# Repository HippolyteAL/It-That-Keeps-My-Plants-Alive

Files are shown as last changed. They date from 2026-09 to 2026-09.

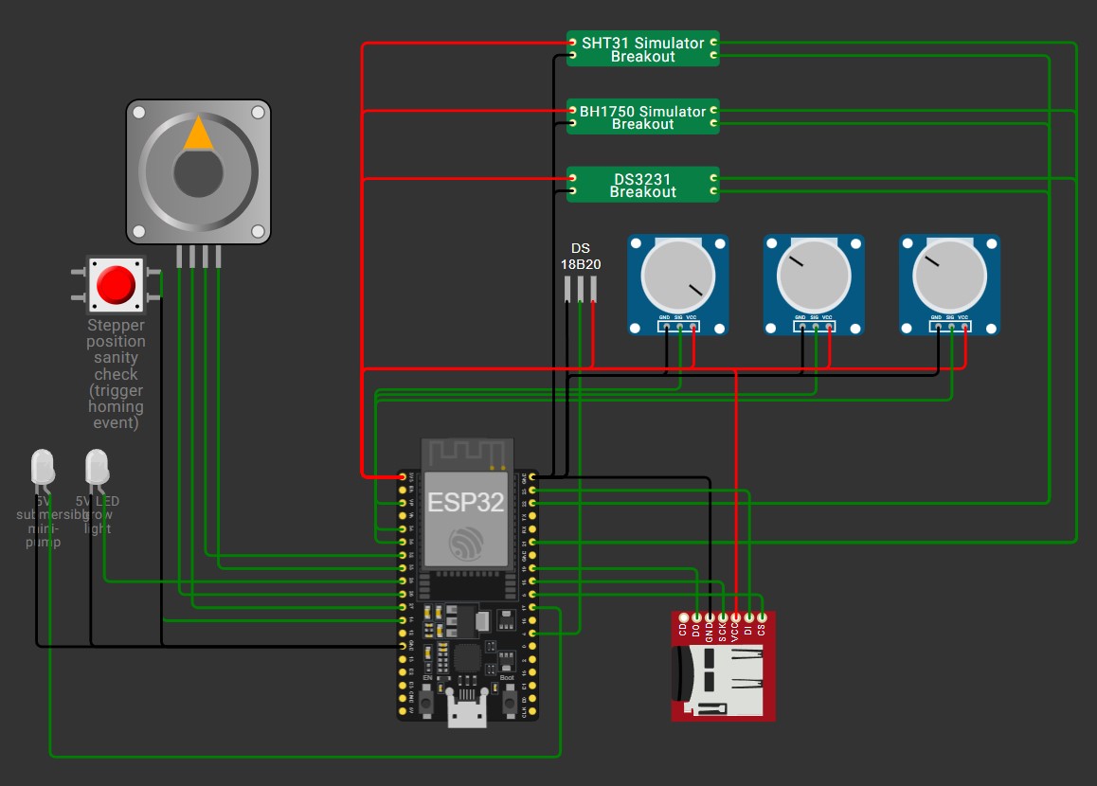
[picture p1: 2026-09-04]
screenshots/diagram_screenshot.jpg

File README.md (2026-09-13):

# It That Keeps My Plants Alive

## Introduction

My houseplants met their untimely demise to the hands of not receiving the proper amount of water, so I have come up with a solution. It's a machine that monitors temperature, humidity and light and controls a grow light and water arm to make sure the plants stay alive. There are also multiple extra sensors to gather various data on ambient humidity/temperature and soil temperature that are unnecessary for the actuator, but I wanted to make something that also gathers data for fun.

## Wokwi simulation

Before getting into any expenses, I decided to run this whole thing in a Wokwi simulation  linked here:

https://wokwi.com/projects/475088516800323585

To run the simulation, download the it_that_keeps_my_plants_alive.bin file from the repo and use the command "F1 -> Upload Firmware and Start Simulation" , uploading the .bin file into the browser.

The soil moisture sensors are replaced with potentiometers in the simulation, so the can be moved around to make the machine water different positions. The downside is that they arent automatically updated when watered and as such are watered repeatedly until manually raised above 30% moisture. All the numerical values are arbitrary placeholders, because real numbers would depend on the real plants being watered. Also the pump is an LED, because it is more visual for a simulation.

This also serves as a good way to picture what this machine is.

## Software architecture
Located in main/, the schematic.pdf pages mirror the structure of the code files.

File | Purpose
---|---
main.c | Main
sensors.c | Periodic sampling of moisture/temp/humidity/light
actuators.c | Pump control + RTC-driven light schedule + stepper control
storage.c | CSV to SD card

## Build

- Install ISP-IDF v5.5.5
- In an ESP-IDF terminal, run the commands:
    - idf.py set-target esp32
    - idf.py build

## Hardware

See the Schematic.pdf, here's an estimate of materials cost (sourced from canadian prices, 2026):

Piece | Function | Cost (pre-tax, CAD)
--- | --- | ---
ESP32-WROOM32E | Main controller | 13$
28BYJ-48 stepper + ULN2003 driver | Motion control | 4$
2x Logic-level MOFSETs | Actuator activation | 2x5$
5V LED grow light | light | 10-20$
5V submersible pump | water | 12$
push switch | control | 1$
DS18B20 | Soil temperature sensor | 15$
3x Soil moisture sensor | Moisture sensor | 3x5$
SHT31 | Ambient temperature and humidity sensor | 12-18$
BH1750 | Light sensor | 7$
DS3231 | Power independant time tracking | 7$
MicroSD module + chip | Logging | 14$
3x 10kΩ resistor | Circuits | variable (bulk vs indiv.)
4.7kΩ resistor | Circuits | variable
1μF capacitor | Circuits | variable
Flyback Diode | Circuits | variable
TOTAL | | ~130 $CAD + electronics + tx

Tools (testing) | Importance | Cost (pre-tax)
--- | --- | ---
Breadboard kit | Essential | 20$
Extra breadboard | Useful | 8$
Multimeter | Variable | 25$
Perfboard | Essential | 2$
TOTAL | | 22-55 $CAD + tx

The total can be brought under 100 $CAD easily if you borrow / already have appropriate tools (or above the current estimate if you choose a more permanent/long term custom circuit board). You can also cut ~50 $CAD by bailing on the purely data gathering part of the project (MicroSD, SHT31, DS18B20).

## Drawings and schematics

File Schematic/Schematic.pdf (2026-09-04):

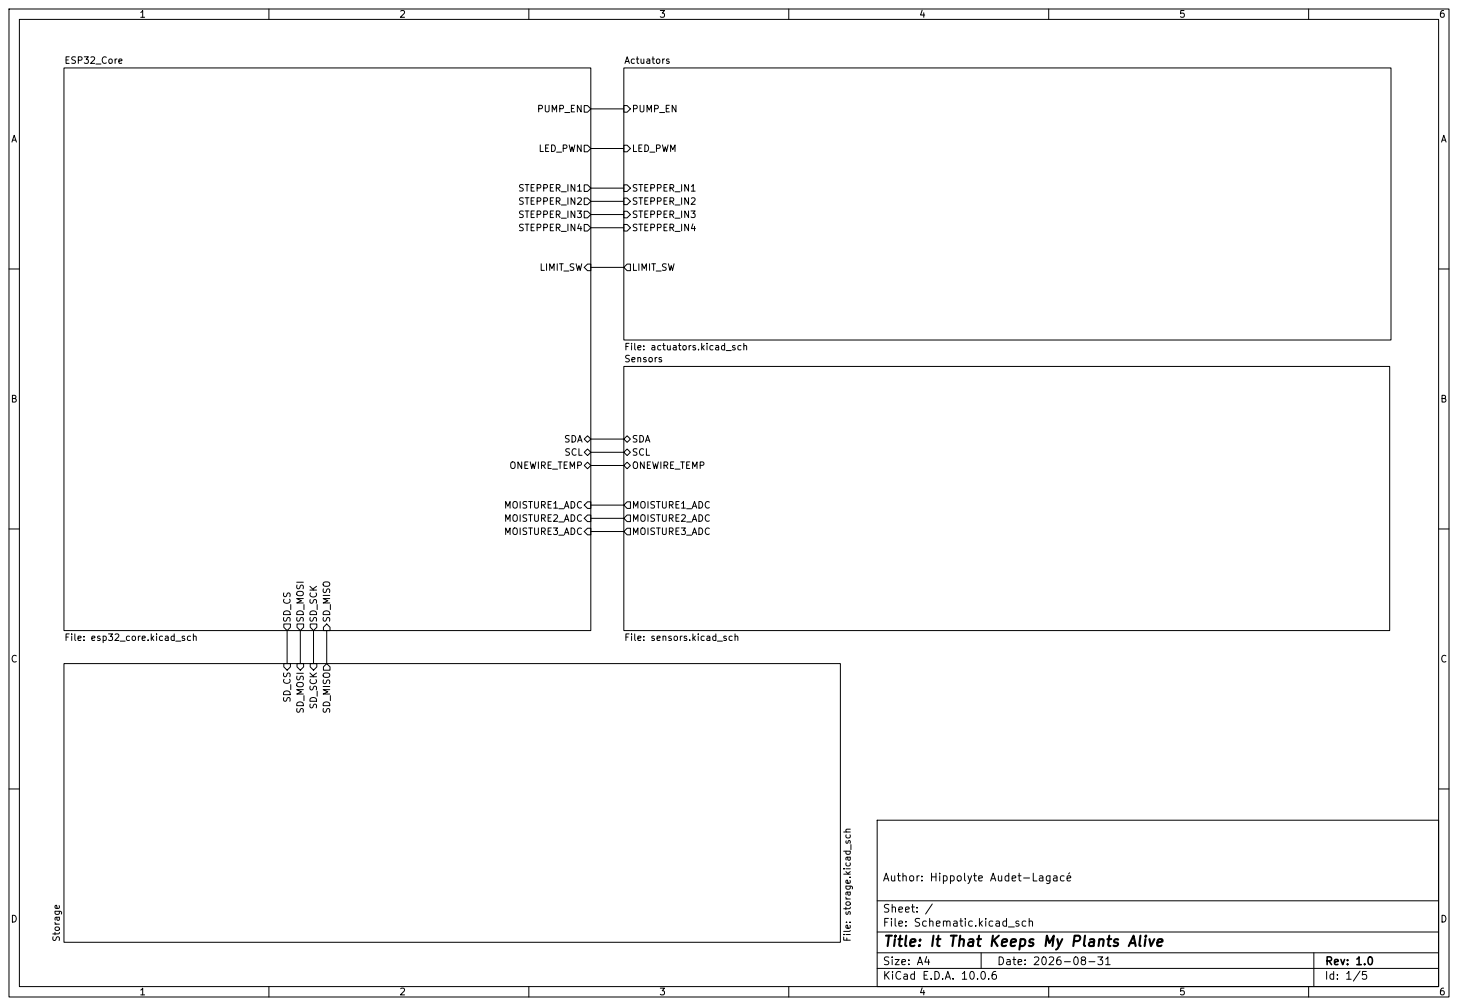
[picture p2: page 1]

Author: Hippolyte Audet-Lagacé MOISTURE1_ADC MOISTURE2_ADC MOISTURE3_ADC ONEWIRE_TEMP

Sheet: /
File: Schematic.kicad_sch
Title: It That Keeps My Plants Alive

Size: A4 | Rev: 1.0
KiCad E.D.A. 10.0.6 | Id: 1/5

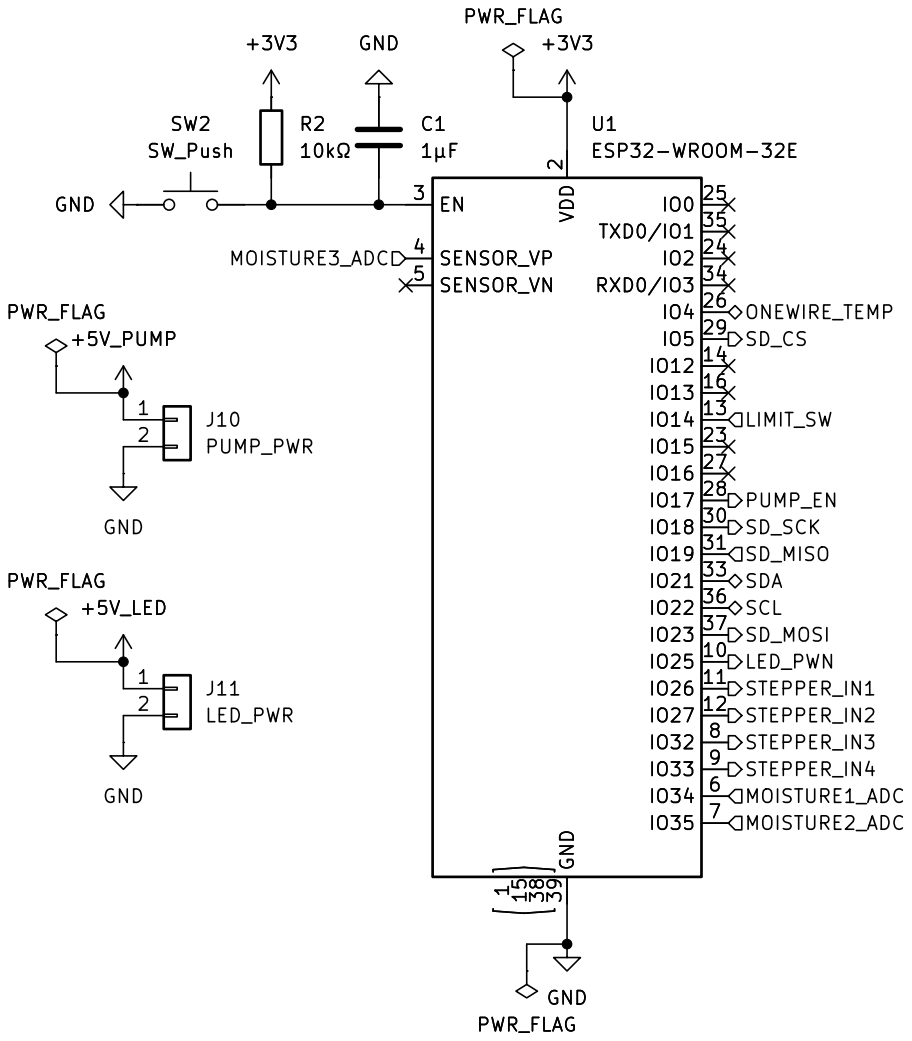
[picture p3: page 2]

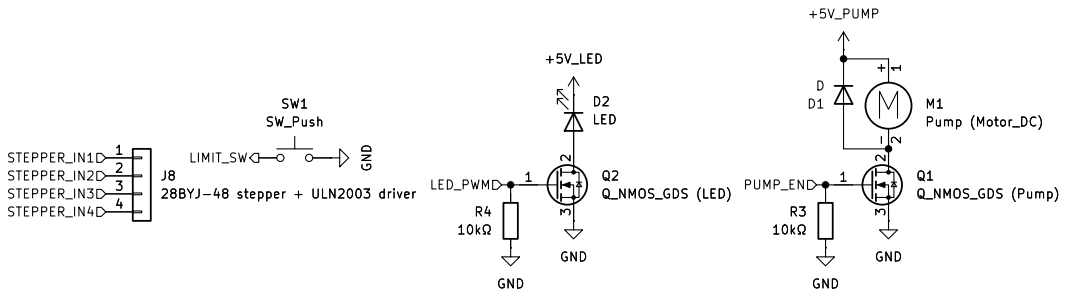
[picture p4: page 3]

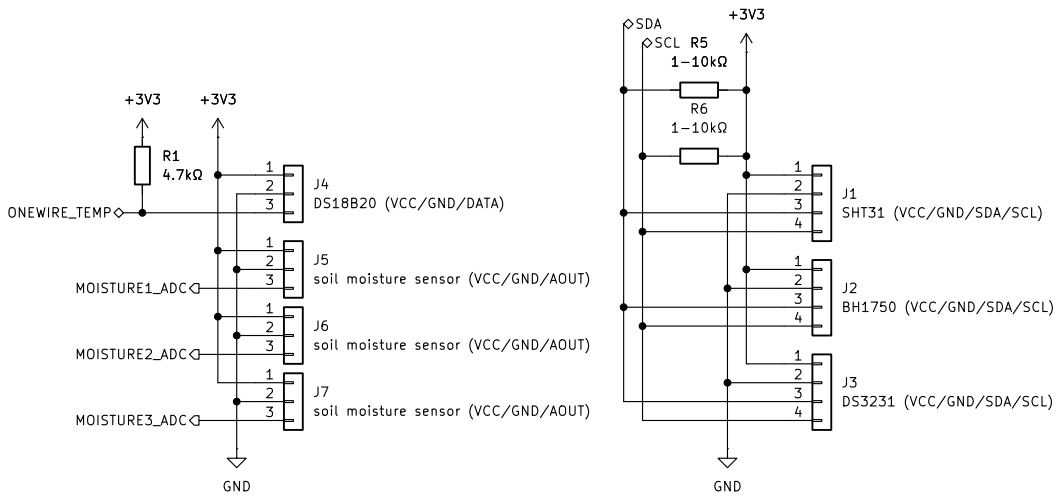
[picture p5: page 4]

soil moisture sensor (VCC/GND/AOUT) 1
J4DS18B20 (VCC/GND/DATA) 1

J3DS3231 (VCC/GND/SDA/SCL) 1
SHT31 (VCC/GND/SDA/SCL) 1

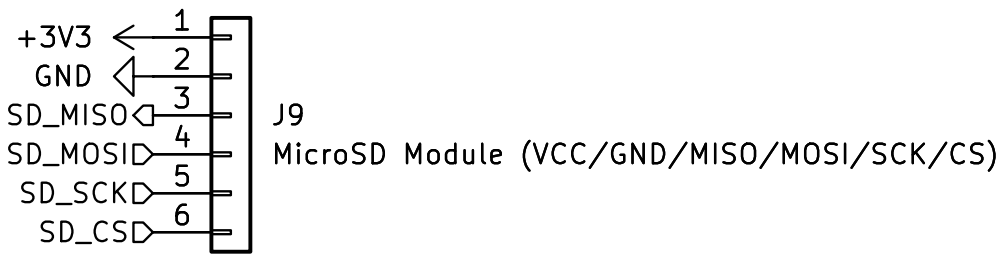
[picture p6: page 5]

J9MicroSD Module (VCC/GND/MISO/MOSI/SCK/CS) SD_CS
SD_MOSI SD_MISO

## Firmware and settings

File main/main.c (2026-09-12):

#include <stdio.h>
#include <stdbool.h>

#include "freertos/FreeRTOS.h"
#include "freertos/task.h"
#include "freertos/semphr.h"

#include "esp_log.h"
#include "esp_err.h"

#include "pinout.h"
#include "sensors.h"
#include "actuators.h"
#include "storage.h"

/*
esp32_core.kicad_sch. Defines and executes the shared system state, task scheduling, 
and the plant-care control loop.
*/

static const char *TAG = "main";

//TODO placeholder values, revisit once sensors are calibrated
#define SENSOR_POLL_PERIOD_MS       (5 * 1000)
#define CONTROL_LOOP_PERIOD_MS      (10 * 1000)
#define LOGGING_PERIOD_MS           (15 * 1000) // TODO: Should be every 15 minutes (15 x 60000) outside of testing ?

#define MOISTURE_LOW_THRESHOLD_PCT  30.0f
#define TARGET_AMBIENT_LUX          8000.0f

// Shared system state: written by sensor_task, read by control_task and logging_task. 
// Guarded by a mutex since it's touched from three tasks.
typedef struct {
    sensor_readings_t   latest;
    SemaphoreHandle_t   mutex;
} system_state_t;

static system_state_t s_state;

static void sensor_task(void *arg);
static void control_task(void *arg);
static void logging_task(void *arg);

void app_main(void) {
    ESP_LOGI(TAG, "boot: It That Keeps My Plants Alive");

    s_state.mutex = xSemaphoreCreateMutex();
    configASSERT(s_state.mutex != NULL);

    ESP_ERROR_CHECK(sensors_init());
    ESP_ERROR_CHECK(actuators_init());
    ESP_ERROR_CHECK(storage_init());
    // ESP_ERROR_CHECK(actuators_stepper_home());

    xTaskCreate(sensor_task,  "sensor_task",  4096, NULL, 5, NULL);
    xTaskCreate(control_task, "control_task", 4096, NULL, 5, NULL);
    xTaskCreate(logging_task, "logging_task", 4096, NULL, 4, NULL);
}

static void sensor_task(void *arg) {
    for (;;) {
        sensor_readings_t reading;
        if (sensors_read_all(&reading) == ESP_OK) {
            xSemaphoreTake(s_state.mutex, portMAX_DELAY);
            s_state.latest = reading;
            xSemaphoreGive(s_state.mutex);

            // testing wokwi setup
            ESP_LOGI(TAG, "sensor_task: rtc=%" PRId64 " soil_temp=%.2fC moisture=[%.1f, %.1f, %.1f]%% " "ambient=%.2fC/%.1f%%RH lux=%.1f",
                    reading.rtc_unix_time, reading.soil_temp_c, reading.soil_moisture_pct[0], reading.soil_moisture_pct[1], 
                    reading.soil_moisture_pct[2], reading.ambient_temp_c, reading.ambient_humidity_pct, reading.ambient_lux);
        } else {
            ESP_LOGW(TAG, "sensor_task: read_all failed");
        }
        vTaskDelay(pdMS_TO_TICKS(SENSOR_POLL_PERIOD_MS));
    }
}

static void control_task(void *arg) {
    for (;;) {
        sensor_readings_t reading;
        xSemaphoreTake(s_state.mutex, portMAX_DELAY);
        reading = s_state.latest;
        xSemaphoreGive(s_state.mutex);

        if (reading.valid) {
            /* TODO: this reacts the instant a probe dips below threshold. The final goal is to require it to stay below threshold for a
            minimum duration first, so a single noisy/borderline reading doesn't trigger a watering cycle, and so watering cycles can be
            potentially executed all at once. This might require moving the homing call outside the watering call to here. */
            for (uint8_t zone = 0; zone < 3; zone++) {
                if (reading.soil_moisture_pct[zone] < MOISTURE_LOW_THRESHOLD_PCT) {
                    ESP_LOGI(TAG, "control_task: zone %u dry (%.1f%%), watering", zone, reading.soil_moisture_pct[zone]);
                    esp_err_t err = actuators_water_zone(zone, reading.rtc_unix_time);
                    if (err != ESP_OK) {
                        ESP_LOGW(TAG, "control_task: water_zone(%u) failed: %s", zone, esp_err_to_name(err));
                    }
                }
            }
            
            uint8_t led_percent = 0;
            actuators_set_led_for_target_lux(reading.ambient_lux, TARGET_AMBIENT_LUX, &led_percent);
            ESP_LOGI(TAG, "control_task: ambient=%.1flux led=%u%% (target=%.0flux)", reading.ambient_lux, led_percent, TARGET_AMBIENT_LUX);
        }

        if (actuators_limit_switch_triggered()) {
            // TODO: decide what a manual homing-button press should do mid-run.
            ESP_LOGI(TAG, "control_task: homing button pressed");
        }

        vTaskDelay(pdMS_TO_TICKS(CONTROL_LOOP_PERIOD_MS));
    }
}

static void logging_task(void *arg) {
    for (;;) {
        sensor_readings_t reading;
        xSemaphoreTake(s_state.mutex, portMAX_DELAY);
        reading = s_state.latest;
        xSemaphoreGive(s_state.mutex);

        if (reading.valid) {
            esp_err_t err = storage_log_reading(&reading);
            if (err != ESP_OK) {
                ESP_LOGW(TAG, "logging_task: write failed (%s)", esp_err_to_name(err));
            }
        }

        vTaskDelay(pdMS_TO_TICKS(LOGGING_PERIOD_MS));
    }
}

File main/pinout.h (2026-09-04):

#ifndef PINOUT_H
#define PINOUT_H

/*
Central pin / bus configuration for the "It That Keeps My Plants Alive" project. Mirrors the net names used on the ESP32_Core sheet of
Schematic.kicad_sch (esp32_core.kicad_sch), which is the hub that the Sensors, Actuators, and Storage sheets all connect back into.

Pin numbers are taken from diagram.json (Wokwi simulation) themselves taken from the KiCad schematic net labels. 
Simulation and real hardware should share the same GPIO map, so this header should not need change between Wokwi and real-hardware builds.
*/

#include "driver/gpio.h"
#include "driver/spi_master.h"
#include "hal/adc_types.h"

//I2C bus (shared by SHT31, BH1750, DS3231 - SCL/SDA nets)/
#define PIN_I2C_SCL                 GPIO_NUM_21
#define PIN_I2C_SDA                 GPIO_NUM_22
#define I2C_MASTER_FREQ_HZ          100000
 
#define I2C_ADDR_SHT31              0x44    // TODO: confirm ADDR pin strap on real hardware 
#define I2C_ADDR_BH1750             0x23    // TODO: confirm ADDR pin strap on real hardware 
#define I2C_ADDR_DS3231             0x68
 
// SPI bus (SD card logger - SD_SCK/SD_MOSI/SD_MISO/SD_CS nets) These line up with the ESP32's default VSPI pins.
#define PIN_SD_SCK                  GPIO_NUM_18
#define PIN_SD_MOSI                 GPIO_NUM_23
#define PIN_SD_MISO                 GPIO_NUM_19
#define PIN_SD_CS                   GPIO_NUM_5
#define SD_SPI_HOST                 SPI3_HOST   // VSPI 
 
// DS18B20 - ONEWIRE_TEMP net
#define PIN_ONEWIRE_TEMP             GPIO_NUM_4
 
/*
Soil moisture ADC inputs (MOISTURE{1,2,3}_ADC nets)
In simulation these are potentiometers (Soil_moisture1/2/3 in diagram.json).
On real hardware, they will be resistive soil moisture probes, same GPIO / ADC channel either way.
*/
#define PIN_MOISTURE1_ADC            GPIO_NUM_34    // ADC1_CH6
#define PIN_MOISTURE2_ADC            GPIO_NUM_35    // ADC1_CH7
#define PIN_MOISTURE3_ADC            GPIO_NUM_36    // ADC1_CH0 (SENSOR_VP / VP) 
 
#define ADC_UNIT_MOISTURE            ADC_UNIT_1
#define ADC_CHANNEL_MOISTURE1        ADC_CHANNEL_6
#define ADC_CHANNEL_MOISTURE2        ADC_CHANNEL_7
#define ADC_CHANNEL_MOISTURE3        ADC_CHANNEL_0
 
// Actuators (LED_PWM, PUMP_EN, LIMIT_SW, STEPPER_IN[1..4] nets)
#define PIN_LED_PWM                  GPIO_NUM_25    // LED grow light, gate of Q2 on real HW
#define PIN_PUMP_EN                  GPIO_NUM_17    // Pump enable, gate of Q1 on real HW
#define PIN_LIMIT_SW                 GPIO_NUM_14    // Homing / limit switch, active-low w/ pull-up
 
/* 
Stepper coil pins (28BYJ-48 via ULN2003 driver board).
TODO: confirm the STEPPER_IN[1..4] -> coil terminal mapping on the physical stepper; the names below follow the coil
terminal labels used in diagram.json (A+/A-/B+/B-), not necessarily the board's [IN1..IN4] order. 
*/
#define PIN_STEPPER_COIL_A_PLUS     GPIO_NUM_27     // STEPPER_IN?
#define PIN_STEPPER_COIL_A_MINUS    GPIO_NUM_26     // STEPPER_IN?
#define PIN_STEPPER_COIL_B_PLUS     GPIO_NUM_32     // STEPPER_IN?
#define PIN_STEPPER_COIL_B_MINUS    GPIO_NUM_33     // STEPPER_IN?
 
#endif /* PINOUT_H */

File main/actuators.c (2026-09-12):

#include "actuators.h"
#include "pinout.h"
#include "storage.h"

#include "esp_log.h"
#include "driver/gpio.h"
#include "driver/ledc.h"

static const char *TAG = "actuators";

// Setup ------------------------------------------------------------------------------------------

#define LEDC_TIMER          LEDC_TIMER_0
#define LEDC_MODE           LEDC_LOW_SPEED_MODE
#define LEDC_CHANNEL_LED    LEDC_CHANNEL_0
#define LEDC_DUTY_RES       LEDC_TIMER_10_BIT           // 0-1023
#define LEDC_FREQUENCY_HZ   5000
#define LEDC_DUTY_MAX       ((1 << LEDC_DUTY_RES) - 1)

// 10% = 1000 lux, dummy values purely for simulation testing
#define LED_LUX_PER_PERCENT    100.0f                   

// 28BYJ-48 does 2048 steps for a full revolution, matching diagram.json's stepper gearRatio
#define STEPS_PER_REV           2048u
#define STEPPER_STEP_DELAY_MS   10   

// Arbitrary for the simulation
#define WATER_PULSE_MS          3000

// Column order matches PIN_STEPPER_COIL_{A_PLUS,A_MINUS,B_PLUS,B_MINUS}
static const uint8_t STEPPER_STEP_TABLE[4][4] = {
    {1, 1, 0, 0},
    {0, 1, 1, 0},
    {0, 0, 1, 1},
    {1, 0, 0, 1},
};
static const gpio_num_t s_stepper_pins[4] = {
    PIN_STEPPER_COIL_A_PLUS, PIN_STEPPER_COIL_A_MINUS,
    PIN_STEPPER_COIL_B_PLUS, PIN_STEPPER_COIL_B_MINUS,
};
// Current position, always kept in [0, STEPS_PER_REV), zeroed by actuators_stepper_home()
static int32_t s_stepper_position   = 0;
// Tracks which row of STEPPER_STEP_TABLE is currently or was last powered
static uint8_t s_stepper_step_index = 0;

// Initialization ---------------------------------------------------------------------------------

// LED grow light, PWM via LEDC, dimmable 0-100%
esp_err_t init_LED(void) {
    esp_err_t err;

    ledc_timer_config_t ledc_timer = {
        .speed_mode      = LEDC_MODE,
        .duty_resolution = LEDC_DUTY_RES,
        .timer_num       = LEDC_TIMER,
        .freq_hz         = LEDC_FREQUENCY_HZ,
        .clk_cfg         = LEDC_AUTO_CLK,
    };
    err = ledc_timer_config(&ledc_timer);
    if (err != ESP_OK) {
        ESP_LOGE(TAG, "ledc_timer_config failed: %s", esp_err_to_name(err));
        return err;
    }
 
    ledc_channel_config_t ledc_channel = {
        .gpio_num   = PIN_LED_PWM,
        .speed_mode = LEDC_MODE,
        .channel    = LEDC_CHANNEL_LED,
        .intr_type  = LEDC_INTR_DISABLE,
        .timer_sel  = LEDC_TIMER,
        .duty       = 0,                    // starts off
        .hpoint     = 0,
    };
    err = ledc_channel_config(&ledc_channel);
    if (err != ESP_OK) {
        ESP_LOGE(TAG, "ledc_channel_config failed: %s", esp_err_to_name(err));
        return err;
    }

    return err;
}

// Pump (LED in the wokwi simulation), digital on/off with a duration
esp_err_t init_PUMP(void) {
    esp_err_t err;

    gpio_config_t pump_conf = {
        .pin_bit_mask = 1ULL << PIN_PUMP_EN,
        .mode         = GPIO_MODE_OUTPUT,
        .pull_up_en   = GPIO_PULLUP_DISABLE,
        .pull_down_en = GPIO_PULLDOWN_DISABLE,
        .intr_type    = GPIO_INTR_DISABLE,
    };
    err = gpio_config(&pump_conf);
    if (err != ESP_OK) {
        ESP_LOGE(TAG, "pump gpio_config failed: %s", esp_err_to_name(err));
        return err;
    }
    gpio_set_level(PIN_PUMP_EN, 0);

    return err;
}

// Limit switch, only makes sense to implement further outside the simulation.
esp_err_t init_limit_switch(void) {
    esp_err_t err;

    gpio_config_t limit_conf = {
        .pin_bit_mask = 1ULL << PIN_LIMIT_SW,
        .mode         = GPIO_MODE_INPUT,
        .pull_up_en   = GPIO_PULLUP_ENABLE,
        .pull_down_en = GPIO_PULLDOWN_DISABLE,
        .intr_type    = GPIO_INTR_DISABLE,
    };
    err = gpio_config(&limit_conf);
    if (err != ESP_OK) {
        ESP_LOGE(TAG, "limit switch gpio_config failed: %s", esp_err_to_name(err));
        return err;
    }

    return err;
}

// Stepper coils, 4 digital outputs initialized unpowered.
esp_err_t init_stepper(void) {
    esp_err_t err;

    gpio_config_t stepper_conf = {
        .pin_bit_mask = (1ULL << PIN_STEPPER_COIL_A_PLUS)  | (1ULL << PIN_STEPPER_COIL_A_MINUS) |
                        (1ULL << PIN_STEPPER_COIL_B_PLUS)  | (1ULL << PIN_STEPPER_COIL_B_MINUS),
        .mode         = GPIO_MODE_OUTPUT,
        .pull_up_en   = GPIO_PULLUP_DISABLE,
        .pull_down_en = GPIO_PULLDOWN_DISABLE,
        .intr_type    = GPIO_INTR_DISABLE,
    };
    err = gpio_config(&stepper_conf);
    if (err != ESP_OK) {
        ESP_LOGE(TAG, "stepper gpio_config failed: %s", esp_err_to_name(err));
        return err;
    }
    for (int i = 0; i < 4; i++) {
        gpio_set_level(s_stepper_pins[i], 0);
    }
    
    return err;
}

esp_err_t actuators_init(void) {
    ESP_LOGI(TAG, "actuators_init");

    esp_err_t err;

    err = init_LED();
    if (err != ESP_OK) {
        return err;
    }

    err = init_PUMP();
    if (err != ESP_OK) {
        return err;
    }

    err = init_limit_switch();
    if (err != ESP_OK) {
        return err;
    }

    err = init_stepper();
    if (err != ESP_OK) {
        return err;
    }

    return err;
}

esp_err_t actuators_set_led_brightness(uint8_t percent) {
    if (percent > 100) {
        return ESP_ERR_INVALID_ARG;
    }

    esp_err_t err;
    uint32_t duty = ((uint32_t)percent * LEDC_DUTY_MAX) / 100;
    
    err = ledc_set_duty(LEDC_MODE, LEDC_CHANNEL_LED, duty);
    if (err != ESP_OK) {
        return err;
    }

    err = ledc_update_duty(LEDC_MODE, LEDC_CHANNEL_LED);
    if (err != ESP_OK) {
        storage_log_error("actuators_set_led_brightness/update_duty", err);
    }
    return err;
}

esp_err_t actuators_set_led_for_target_lux(float ambient_lux, float target_lux, uint8_t *out_percent) {
    float deficit = target_lux - ambient_lux;
    float percent_f = deficit / LED_LUX_PER_PERCENT;
    
    if (percent_f < 0.0f) {
        percent_f = 0.0f;
    } else if (percent_f > 100.0f) {
        percent_f = 100.0f;
    }
    
    uint8_t percent = (uint8_t)(percent_f + 0.5f);  // rounding to nearest
    
    esp_err_t err = actuators_set_led_brightness(percent);
    if (err == ESP_OK && out_percent != NULL) {
        *out_percent = percent;
    }
    return err;
}

esp_err_t actuators_set_pump(bool enabled) {
    esp_err_t err = gpio_set_level(PIN_PUMP_EN, enabled ? 1 : 0);
    if (err != ESP_OK) {
        storage_log_error("actuators_set_pump", err);
    }
    return err;
}
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

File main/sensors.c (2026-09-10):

#include "sensors.h"
#include "pinout.h"
 
#include <stddef.h>
 
#include "esp_log.h"
#include "esp_adc/adc_oneshot.h"
#include "driver/i2c_master.h"
#include "driver/gpio.h"
#include "esp_rom_sys.h"
#include "freertos/FreeRTOS.h"
#include "freertos/task.h"

static const char *TAG = "sensors";

// I2C + ADC handles*/
static i2c_master_bus_handle_t   s_i2c_bus     = NULL;
static i2c_master_dev_handle_t   s_dev_sht31   = NULL;
static i2c_master_dev_handle_t   s_dev_bh1750  = NULL;
static i2c_master_dev_handle_t   s_dev_ds3231  = NULL;
static adc_oneshot_unit_handle_t s_adc_handle  = NULL;
static const adc_channel_t s_moisture_channels[3] = {
    ADC_CHANNEL_MOISTURE1, ADC_CHANNEL_MOISTURE2, ADC_CHANNEL_MOISTURE3
};

/*
SIMULATION-ONLY: Wokwi has no soil moisture sensor part, so J5/J6/J7
are stood in for by potentiometers (Soil_moisture[1/2/3] in diagram.json). 
This maps a raw ADC count to an arbitrary 0-100% moisture reading so the rest 
of the code doesn't need to care about the substitution.

TODO: replace with a real calibration curve once the resistive probes
are the actual sensors.
*/

#define POT_ADC_MAX_RAW 4095.0f // ADC_BITWIDTH_DEFAULT is 12-bit on ESP32 (2^12 = 4096)

static float potentiometer_to_moisture_pct(int raw_counts){
    float pct = ((float)raw_counts / POT_ADC_MAX_RAW) * 100.0f;
    if (pct > 100.0f) {
        pct = 100.0f;
    } else if (pct < 0.0f) {
        pct = 0.0f;
    }
    return pct;
}

// Onewire helpers --------------------------------------------------------------------------------

#define ONEWIRE_CMD_SKIP_ROM         0xCC
#define DS18B20_CMD_CONVERT_T        0x44
#define DS18B20_CMD_READ_SCRATCHPAD  0xBE
static portMUX_TYPE s_onewire_mux = portMUX_INITIALIZER_UNLOCKED;

static bool onewire_reset_pulse(void) {
    gpio_set_level(PIN_ONEWIRE_TEMP, 0);    // resets pulse and hold low
    esp_rom_delay_us(480);
    gpio_set_level(PIN_ONEWIRE_TEMP, 1);   // releases and wait for a presence pulse (pulling low)
    esp_rom_delay_us(70);
    bool presence = (gpio_get_level(PIN_ONEWIRE_TEMP) == 0);
    esp_rom_delay_us(410);
    return presence;    // returns true if a device pulled the bus low in response
}

static void onewire_write_bit(bool bit) {
    taskENTER_CRITICAL(&s_onewire_mux);
    if (bit) {
        gpio_set_level(PIN_ONEWIRE_TEMP, 0);
        esp_rom_delay_us(6);
        gpio_set_level(PIN_ONEWIRE_TEMP, 1);
        esp_rom_delay_us(64);
    } else {
        gpio_set_level(PIN_ONEWIRE_TEMP, 0);
        esp_rom_delay_us(60);
        gpio_set_level(PIN_ONEWIRE_TEMP, 1);
        esp_rom_delay_us(10);
    }
    taskEXIT_CRITICAL(&s_onewire_mux);
}
static bool onewire_read_bit(void) {
    bool bit;
    taskENTER_CRITICAL(&s_onewire_mux);
    gpio_set_level(PIN_ONEWIRE_TEMP, 0);
    esp_rom_delay_us(6);
    gpio_set_level(PIN_ONEWIRE_TEMP, 1);
    esp_rom_delay_us(9);
    bit = (gpio_get_level(PIN_ONEWIRE_TEMP) != 0);
    esp_rom_delay_us(55);
    taskEXIT_CRITICAL(&s_onewire_mux);
    return bit;
}
static void onewire_write_byte(uint8_t byte) {
    for (int i = 0; i < 8; i++) {
        onewire_write_bit(byte & 0x01);
        byte >>= 1;
    }
}
static uint8_t onewire_read_byte(void) {
    uint8_t byte = 0;
    for (int i = 0; i < 8; i++) {
        byte >>= 1;
        if (onewire_read_bit()) {
            byte |= 0x80;
        }
    }
    return byte;
}

// Dallas/Maxim CRC8 (poly x^8+x^5+x^4+1, reflected 0x8C), used to verify the DS18B20 scratchpad.
static uint8_t onewire_crc8(const uint8_t *data, size_t len) {
    uint8_t crc = 0;
    for (size_t i = 0; i < len; i++) {
        uint8_t in_byte = data[i];
        for (int b = 0; b < 8; b++) {
            uint8_t mix = (crc ^ in_byte) & 0x01;
            crc >>= 1;
            if (mix) {
                crc ^= 0x8C;
            }
            in_byte >>= 1;
        }
    }
    return crc;
}

// Sensirion CRC8 (poly x^8+x^5+x^4+1 = 0x31, non-reflected, init 0xFF), used to verify each 16-bit word from SHT31
static uint8_t sensirion_crc8(const uint8_t *data, size_t len) {
    uint8_t crc = 0xFF;
    for (size_t i = 0; i < len; i++) {
        crc ^= data[i];
        for (int b = 0; b < 8; b++) {
            crc = (crc & 0x80) ? (uint8_t)((crc << 1) ^ 0x31) : (uint8_t)(crc << 1);
        }
    }
    return crc;
}

// DS3231 helpers ---------------------------------------------------------------------------------

// NOTE:  The DS3231 is treated as UTC since it is the most common from what i found, but this could have to be changed
// algorithms from: https://howardhinnant.github.io/date_algorithms.html

static inline uint8_t bcd_to_dec(uint8_t bcd) {
    return (uint8_t)(((bcd >> 4) * 10) + (bcd & 0x0F));
}
static inline uint8_t dec_to_bcd(uint8_t dec) {
    return (uint8_t)(((dec / 10) << 4) | (dec % 10));
}

static int64_t civil_to_unix(int year, int month, int day, int hour, int min, int sec) {
    int64_t y = year;
    y -= (month <= 2);
    int64_t era = (y >= 0 ? y : y - 399) / 400;
    unsigned yoe = (unsigned)(y - era * 400);
    unsigned doy = (153 * (month + (month > 2 ? -3 : 9)) + 2) / 5 + (unsigned)day - 1;
    unsigned doe = yoe * 365 + yoe / 4 - yoe / 100 + doy;
    int64_t days = era * 146097 + (int64_t)doe - 719468;    // days since 1970-01-01
    return days * 86400 + hour * 3600 + min * 60 + sec;
}
static void unix_to_civil(int64_t unix_time, int *year, int *month, int *day, int *hour, int *min, int *sec) {
    int64_t days = unix_time / 86400;
    int64_t rem = unix_time % 86400;
    if (rem < 0) {
        rem += 86400;
        days -= 1;
    }
    *hour = (int)(rem / 3600);
    *min  = (int)((rem % 3600) / 60);
    *sec  = (int)(rem % 60);
    
    int64_t z = days + 719468;
    int64_t era = (z >= 0 ? z : z - 146096) / 146097;
    unsigned doe = (unsigned)(z - era * 146097);
    unsigned yoe = (doe - doe / 1460 + doe / 36524 - doe / 146096) / 365;
    int64_t y = (int64_t)yoe + era * 400;
    unsigned doy = doe - (365 * yoe + yoe / 4 - yoe / 100);
    unsigned mp = (5 * doy + 2) / 153;
    int m = (int)mp + (mp < 10 ? 3 : -9);
    int d = (int)(doy - (153 * mp + 2) / 5 + 1);
    
    *year  = (int)(y + (m <= 2));
    *month = m;
    *day   = d;
}

// Initialization ---------------------------------------------------------------------------------
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

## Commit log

2026-09-04 Added code skeleton, schematics.pdf, and updated the README to a decent state.
2026-09-09 Implemented sensors, waiting for logging implementation to test, backlogged CRC mismatch in temp reading.
2026-09-12 Fixed stepper, further work needs storage data access (available on browser)
    [actuators.c, main.c, storage.c]
2026-09-13 De-engineered the overengineered DS3231 RTC custom chip to fix needless bugs
    [DS3231.chip.c]
